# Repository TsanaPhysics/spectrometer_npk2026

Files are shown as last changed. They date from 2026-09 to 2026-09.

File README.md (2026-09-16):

# เครื่องสเปกโทรโฟโตมิเตอร์ตรวจวัดธาตุอาหารหลักในดินและสมบัติเชิงแสงของของเหลว (spectrometer_npk2026)

<p align="center">
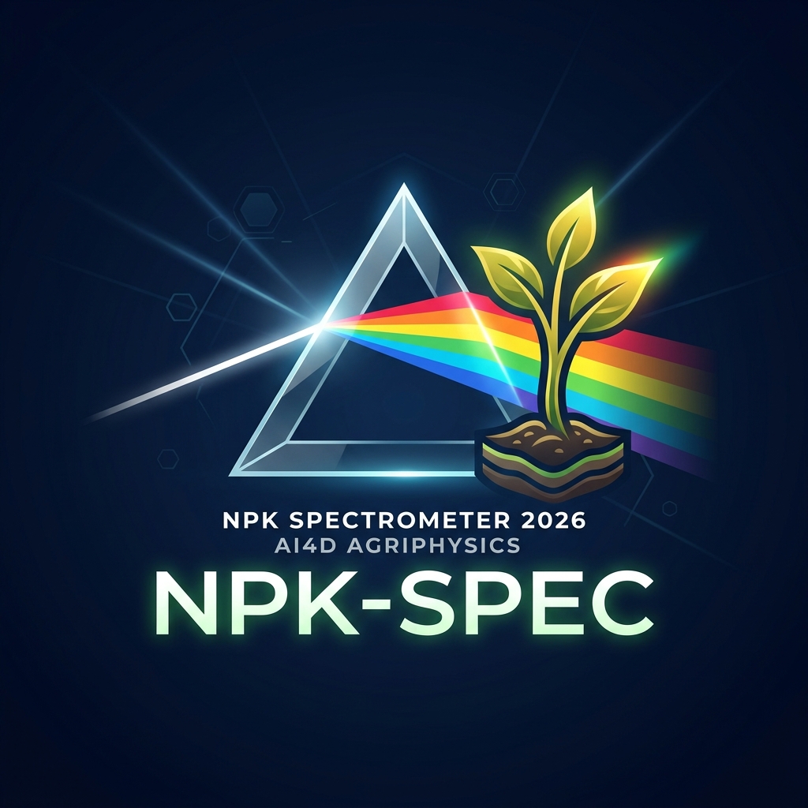
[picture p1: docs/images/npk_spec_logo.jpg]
NPK Spectrometer Logo
  
</p>

<h2 align="center"><b>เครื่องสเปกโทรโฟโตมิเตอร์ตรวจวัดธาตุอาหารหลักในดินและสมบัติเชิงแสงของของเหลว</b></h2>
<h3 align="center"><b>(NPK Level Meter 1.02 & Liquid Optics Metrology Analyzer)</b></h3>

<p align="center">
  
  
  
  
  
  
  
</p>

<p align="center">
  <b>ระบบสเปกโทรโฟโตมิเตอร์แบบพกพา 8 หน้าจอ (8-Screen Carousel UI) ผสาน Edge AI TinyML ในตัว, การสร้างกราฟมาตรฐานสด (In-Situ Standard Curve: R², LOD, LOQ), ระบบสลับความยาวคลื่นแสงอัตโนมัติ (Auto-Wavelength Switching), และการวิเคราะห์ pH ดินและสมบัติเชิงแสงของของเหลว</b><br>
  <i>หน่วยวิจัยเกษตรดิจิทัล JC_AI_SciRBRU (Digital Agriphysics & AI Research Unit, JC_AI_SciRBRU) สาขาวิชาฟิสิกส์ คณะวิทยาศาสตร์และเทคโนโลยี มหาวิทยาลัยราชภัฏรำไพพรรณี</i>
</p>

---

## สารบัญ (Table of Contents)
- [ภาพรวมโครงการ (Project Overview)](#ภาพรวมโครงการ-project-overview)
- [สถาปัตยกรรม 8 หน้าจอ (8-Screen Carousel UI)](#สถาปัตยกรรม-8-หน้าจอ-8-screen-carousel-ui)
- [ระบบเปลี่ยนความยาวคลื่นแสงอัตโนมัติ (Auto-Wavelength Switching)](#ระบบเปลี่ยนความยาวคลื่นแสงอัตโนมัติ-auto-wavelength-switching)
- [ทฤษฎีทางฟิสิกส์และเคมีวิเคราะห์ (Physics & Metrology Theory)](#ทฤษฎีทางฟิสิกส์และเคมีวิเคราะห์-physics--metrology-theory)
  - [1. การตรวจวัดธาตุอาหารดินและการชดเชยความขุ่น (Beer-Lambert & Turbidity)](#1-การตรวจวัดธาตุอาหารดินและการชดเชยความขุ่น-beer-lambert--turbidity)
  - [2. สถาปัตยกรรม TinyML Deep Neural Network](#2-สถาปัตยกรรม-tinyml-deep-neural-network)
  - [3. ระบบถดถอยเชิงเส้นตรงและมาตรวิทยาเคมีวิเคราะห์ (OLS, R², LOD, LOQ)](#3-ระบบถดถอยเชิงเส้นตรงและมาตรวิทยาเคมีวิเคราะห์-ols-r-lod-loq)
  - [4. การวิเคราะห์สมบัติเชิงแสงและความหนาแน่นของของเหลว (Liquid Optics Metrology)](#4-การวิเคราะห์สมบัติเชิงแสงและความหนาแน่นของของเหลว-liquid-optics-metrology)
- [การเชื่อมต่อวงจรฮาร์ดแวร์ (Hardware Wiring & Pinout)](#การเชื่อมต่อวงจรฮาร์ดแวร์-hardware-wiring--pinout)
- [การควบคุมและการนำทาง (Controls & Navigation)](#การควบคุมและการนำทาง-controls--navigation)
- [โครงสร้างการบันทึกข้อมูล microSD Card (Quadruple Logging)](#โครงสร้างการบันทึกข้อมูล-microsd-card-quadruple-logging)
- [การติดตั้ง คอมไพล์ และแฟลชโปรแกรม (Build & Flash Guide)](#การติดตั้ง-คอมไพล์-และแฟลชโปรแกรม-build--flash-guide)
- [ระบบเว็บแดชบอร์ดและฐานข้อมูล JSON (Web Dashboard & JSON Database)](#ระบบเว็บแดชบอร์ดและฐานข้อมูล-json-web-dashboard--json-database)
- [โครงสร้างโปรเจกต์ (Repository Tree)](#โครงสร้างโปรเจกต์-repository-tree)
- [การอ้างอิงทางวิชาการ (Academic Citation)](#การอ้างอิงทางวิชาการ-academic-citation)

---

## ภาพรวมโครงการ (Project Overview)

เครื่อง **สเปกโทรโฟโตมิเตอร์ตรวจวัดธาตุอาหารหลักในดินและสมบัติเชิงแสงของของเหลว (NPK Level Meter 1.02 & Liquid Optics Metrology Analyzer)** พัฒนาโดย **หน่วยวิจัยเกษตรดิจิทัล JC_AI_SciRBRU** เป็นระบบตรวจวัดทางเคมีฟิสิกส์เชิงสเปกตรัมแบบพกพาที่พัฒนาขึ้นสำหรับเกษตรกรแปลงใหญ่ (เช่น สวนทุเรียนจันทบุรี) นักวิจัย และห้องปฏิบัติการวิทยาศาสตร์ โดยมีจุดเด่นคือ:
1. **ประมวลผลบนชิปสมบูรณ์ 100% (Edge-Only Processing):** ใช้ไมโครคอนโทรลเลอร์ Microchip ATSAMD51P19A (ARM Cortex-M4F 120 MHz พร้อม Hardware FPU) ไม่พึ่งพาคลาวด์หรือสมาร์ตโฟน
2. **ระบบการวิเคราะห์ 3 โหมด (Triple Analytical Engine):** สลับโหมดวิเคราะห์ธาตุอาหารดินระหว่าง TinyML Neural Network, Classical Polynomial และ In-Situ Standard Curve ได้ทันที
3. **ระบบสลับความยาวคลื่นแสงอัตโนมัติ (Auto-Wavelength Switching):** ปรับสีและความยาวคลื่นของแสง LED อัตโนมัติตามหน้าจอการวิเคราะห์ (Blue 465 nm สำหรับ N, Red 625 nm สำหรับ P และ K, Green/Red สำหรับ pH)
4. **ระบบสร้างเส้นโค้งมาตรฐานในตัวเครื่อง (In-Situ Calibration Wizard):** คำนวณความชัน $m$, จุดตัด $c$, ค่า $R^2$, LOD, LOQ ตามมาตรฐาน IUPAC/ISO 17025
5. **ระบบวิเคราะห์ความเป็นกรดด่างและสมบัติของเหลว (Soil pH & Liquid Optics):** ตรวจวัดค่า pH ดิน พร้อมคำแนะนำสำหรับสวนทุเรียน และตรวจวัดค่าดัชนีหักเห ($n$), ความหนาแน่น ($\rho$ ใน $\text{g/cm}^3$), ความเข้มข้นสารละลาย ($^\circ\text{Bx}$)
6. **ระบบการแสดงผลแบบ High-Contrast Zero-Tofu UI:** ปราศจากปัญหากล่องสี่เหลี่ยมเต้าหู้ (`[][][]`) และไร้ปัญหาข้อความซ้อนทับกัน พร้อมระบบนาฬิกา RTC ปรับเทียบเวลาจริงอัตโนมัติ (`__TIME__`, `__DATE__`)
7. **เอกลักษณ์แบรนดิ้งวิจัยเฉพาะ `JC_AI_SciRBRU`:** ออกแบบตราสัญลักษณ์หลากสีระดับพรีเมียม (JC แดง, AI ส้ม, Sci เหลือง, RBRU เขียว)

---

## สถาปัตยกรรม 8 หน้าจอ (8-Screen Carousel UI)

ผู้ใช้สามารถสลับหน้าจอได้อย่างราบรื่นผ่านจอยสติ๊ก 5 ทิศทาง (`WIO_5S_LEFT / RIGHT`):

```
 [1/8] Dashboard ──> [2/8] Nitrogen (N) ──> [3/8] Phosphorus (P) ──> [4/8] Potassium (K)
        │
        └───> [5/8] Soil pH ──> [6/8] NPK Matrix ──> [7/8] Calib Wizard ──> [8/8] System Info
```

### รายละเอียดหน้าจอทั้ง 8 หน้า:
1. **Page 1: System Dashboard (`[1/8]`):**
   - หัวข้อ **"สเปกโทรโฟโตมิเตอร์"** จัดกึ่งกลางจอและขยายขนาดใหญ่ขึ้น 10% เพื่อความชัดเจนและสมดุล
   - แบรนด์ระดับพรีเมียม **`SpecJC +AI Analyzer`** จัดกึ่งกลางจอ ขยายขนาดใหญ่ขึ้น 10% (Spec สีฟ้าสด `0x07FF`, JC สีแดงสด `TFT_RED`, +AI สีเหลืองทอง `TFT_YELLOW`, Analyzer สีเขียวสดใส `TFT_GREEN`) พร้อมป้ายสถานะโมเดล **`AI TinyML`** (ลดขนาดและตัดวงเล็บ [ ] ออกเพื่อความกะทัดรัด)
   - ตราสัญลักษณ์เวกเตอร์ออปติคัลปริซึมและสเปกตรัมแสง 5 สี
   - ตรวจสอบความพร้อมของระบบ: SAMD51 120 MHz, FPU, หน่วยความจำ Flash/SRAM, เซนเซอร์ TCS34725, microSD Card, และนาฬิกา RTC ปรับเทียบเวลาจริงอัตโนมัติ (ปรับตำแหน่งต่ำลงมาเพื่อป้องกันการบดบังและซ้อนทับ)
2. **Page 2: Dedicated Nitrogen Assay (`[2/8]`):**
   - หัวข้อ **"วิเคราะห์ปริมาณไนโตรเจน"** จัดกึ่งกลางจออย่างแม่นยำ (สีฟ้า Cyan `0x07FF`)
   - หลอดไฟ LED ปรับเข้าสู่แสงสีน้ำเงินความยาวคลื่นแม่นยำ **465 nm Blue LED** โดยอัตโนมัติ
   - แสดงค่าความเข้มข้นไนโตรเจนแบบเรียลไทม์ พร้อมตัวอักษร **`N` ขนาดใหญ่พิเศษ (TextSize 4) ตัวหนา สีชมพูอมม่วง (Magenta)** ต่อท้ายหน่วย $\text{mg/kg}$
   - แถบสเกลวัดระดับยกสูงขึ้น ($y=126..134$) ป้องกันการซ้อนทับกับข้อความประเมินระดับธาตุอาหารภาษาไทย
   - ป้ายกำกับโหมด `AI TinyML`, `PL Poly`, หรือ `SC StdCurv`
3. **Page 3: Dedicated Phosphorus Assay (`[3/8]`):**
   - หัวข้อ **"วิเคราะห์ปริมาณฟอสฟอรัส"** จัดกึ่งกลางจออย่างแม่นยำ (สีเขียวสดใส `TFT_GREEN`)
   - หลอดไฟ LED ปรับเข้าสู่แสงสีแดงความยาวคลื่น **625 nm Red LED** โดยอัตโนมัติ (Molybdenum Blue Absorption Peak)
   - แสดงค่าความเข้มข้นฟอสฟอรัสแบบเรียลไทม์ พร้อมตัวอักษร **`P` ขนาดใหญ่พิเศษ (TextSize 4) ตัวหนา สีฟ้าสด (Cyan `0x07FF`)**
   - หน่วย $\text{mg/kg}$ ปรับเลื่อนออกไปที่ตำแหน่งพิกัด $x=172$ (+10px) พร้อมจัดวางค่าการดูดกลืนแสง $A_{625}$ และแท็กสถานะที่พิกัด $x=172$ เพื่อความสวยงามลงตัว ไม่เบียดชิดกับตัวเลขความเข้มข้น
   - แถบสเกลยกสูงขึ้น ป้องกันการบดบังข้อความผลการวิเคราะห์ภาษาไทย
   - ผสานแบบจำลองการอนุมานแสงฉบับปรับปรุง (Revised Optical Inference): แม่นยำสูงพิเศษในช่วง $1.0 - 6.0\text{ mg/L}$ ($R^2 = 0.9944, \text{RMSE} = 0.144\text{ mg/L}$) พร้อมระบบ **Saturation Guard** เตือนการเจือจางตัวอย่าง (Dilution Alert) เมื่อค่าการดูดกลืนแสงเกินช่วงเชิงเส้นตรง $A > 0.500$ ($> 6.0\text{ mg/L}$)
4. **Page 4: Dedicated Potassium Assay (`[4/8]`):**
   - หัวข้อ **"วิเคราะห์ปริมาณโพแทสเซียม"** จัดกึ่งกลางจออย่างแม่นยำ (สีแดงสด `TFT_RED`)
   - หลอดไฟ LED ปรับเข้าสู่แสงสีแดงความยาวคลื่น **625 nm Red LED** โดยอัตโนมัติ
   - แสดงค่าความเข้มข้นโพแทสเซียมแบบเรียลไทม์ พร้อมตัวอักษร **`K` ขนาดใหญ่พิเศษ (TextSize 4) ตัวหนา สีแดงสด (Red)** ต่อท้ายหน่วย $\text{mg/kg}$
   - แถบสเกลยกสูงขึ้น ป้องกันการบดบังข้อความผลการวิเคราะห์ภาษาไทย
5. **Page 5: Soil pH Assay (`[5/8]`):**
   - หัวข้อ **"วิเคราะห์ความเป็นกรด ด่าง"** จัดกึ่งกลางจออย่างแม่นยำ (สีเหลืองนีออน `TFT_YELLOW`)
   - หลอดไฟ LED ปรับเป็นโหมดตรวจวัดสีย้อมอินดิเคเตอร์คู่ความยาวคลื่น **525/625 nm**
   - แสดงข้อความ **`pH Level` ขนาดใหญ่ (TextSize 3) ตัวหนา Multi-Pass Rendering พร้อมคู่สีสันสดใส (`pH` สีฟ้าสดใส Neon Cyan `0x07FF` และ `Level` สีเหลืองนีออน Bright Yellow `TFT_YELLOW`)**
   - กราฟิกแท่งสเกลวัดความเป็นกรดด่างเชิงแสง ($3.5 - 8.5\text{ pH}$) ปรับตำแหน่งยกสูงขึ้น ป้องกันการบดบังข้อความ พร้อมระบบวินิจฉัยและคำแนะนำการปรับปรุงดินเฉพาะทางสำหรับสวนทุเรียน
6. **Page 6: Full NPK Nutrient Matrix (`[6/8]`):**
   - หน้าจอรวมตารางธาตุอาหารหลักทั้ง 3 ชนิด (N, P, K) ในหน้าเดียว พร้อมแถบกราฟิกแสดงระดับธาตุอาหาร (ต่ำ-เหมาะสม-สูง)
7. **Page 7: Calibration & Standard Curve Wizard (`[7/8]`):**
   - ฝั่งซ้าย: กราฟิกแสดงเส้นตรงการถดถอยและจุดข้อมูลจริง 5 จุดความเข้มข้น ($0, 20, 40, 80, 160\text{ mg/kg}$)
   - ฝั่งขวา: แผงสถิติมาตรวิทยาเคมีวิเคราะห์ ($R^2$, ความชัน $m$, จุดตัด $c$, LOD, LOQ ตามมาตรฐาน IUPAC/ISO 17025)
   - ปุ่มเลือกธาตุ: ปุ่ม C (ไนโตรเจน 465 nm), ปุ่ม B (ฟอสฟอรัส 525 nm), ปุ่ม A (โพแทสเซียม 625 nm)
8. **Page 8: System Diagnostics & Core Info (`[8/8]`):**
   - ตรวจสอบรายละเอียดสถานะฮาร์ดแวร์ การจัดการพลังงาน สวิตช์สลับโมเดลคำนวณ (แสดงผล AI TinyML แบบไม่มีวงเล็บ)
   - ข้อมูลและเครดิตผู้วิจัย: **ผศ.ดร.ชีวะ ทัศนา** และ **ผศ.ดร.จิรภัทร จันทมาลี** (ปรับขนาดฟอนต์กะทัดรัดลงตัว ปราศจากการบดบังข้อมูล) พร้อมแบรนดิ้ง **`SpecJC +AI Analyzer`**

---

## ระบบเปลี่ยนความยาวคลื่นแสงอัตโนมัติ (Auto-Wavelength Switching)

ระบบเฟิร์มแวร์ได้รับการออกแบบให้มีฟังก์ชัน **Auto-Optics Wavelength Switching Engine** เพื่อลดความผิดพลาดของผู้ใช้งาน (Zero Human Error) โดยฮาร์ดแวร์จะเปลี่ยนสีและความยาวคลื่นของแหล่งกำเนิดแสง LED ทันทีที่ผู้ใช้เปลี่ยนหน้าจอ:

| หน้าจอที่กำลังแสดงผล | แหล่งกำเนิดแสง LED ที่เปิดอัตโนมัติ | ความยาวคลื่นแสง ($\lambda$) | เหตุผลทางเคมีฟิสิกส์เชิงแสง |
| :--- | :--- | :--- | :--- |
| **Page 2: Nitrogen (N)** | **Blue LED** | $\approx 465\text{ nm}$ | ดูดกลืนแสงสูงสุดในสารละลายสกัดไนเตรต/แอมโมเนีย (สีส้มอมน้ำตาล) |
| **Page 3: Phosphorus (P)** | **Red LED** | $\approx 625\text{ nm}$ | ดูดกลืนแสงสูงสุดในสารเชิงซ้อนฟอสโฟโมลิบดีนัมบลู (Molybdenum Blue) |
| **Page 4: Potassium (K)** | **Red LED** | $\approx 625\text{ nm}$ | วัดการกระเจิงแสงและการลดทอนความเข้มของตะกอนเตตระฟีนิลบอเรต |
| **Page 5: Soil pH** | **Dual Green/Red** | $\approx 525\text{ / }625\text{ nm}$ | วัดอัตราส่วนการดูดกลืนแสงของสีย้อม Universal / Bromothymol Blue |
| **Page 7: Calibration** | **ตามธาตุที่เลือก (C/B/A)** | $465\text{ / }525\text{ / }625\text{ nm}$ | ปรับตามธาตุอาหารมาตรฐานที่กำลังเทียบเส้นกราฟ |
| **Page 1, 6, 8 (Dashboard/Info)** | **Standby (Off/White)** | Full Spectrum / Off | พักแหล่งกำเนิดแสงเพื่อประหยัดพลังงานและยืดอายุการใช้งาน |

---

## ทฤษฎีทางฟิสิกส์และเคมีวิเคราะห์ (Physics & Metrology Theory)

### 1. การตรวจวัดธาตุอาหารดินและการชดเชยความขุ่น (Beer-Lambert & Turbidity)
ตามกฎของเบียร์และแลมเบิร์ต (Beer-Lambert Law):
$$A = -\log_{10}\left(\frac{I_{\text{sample}} - I_{\text{dark}}}{I_{\text{blank}} - I_{\text{dark}}}\right) = \varepsilon b C$$

ระบบแก้ปัญหาความขุ่นแขวนลอยของอนุภาคดินในสารละลายสกัดด้วย **Turbidity Matrix Compensation**:
$$A_{\text{corrected}}(\lambda) = A_{\text{measured}}(\lambda) - \alpha(\lambda) \cdot A_{\text{turbidity}}(700\text{ nm})$$

### 2. สถาปัตยกรรม TinyML Deep Neural Network
โครงข่ายประสาทเทียม Multi-Layer Perceptron ($6 \to 12 \to 8 \to 3$) ประมวลผลด้วย C++ Zero-Allocation Inference Engine:
- **เวกเตอร์นำเข้า (6 Features):** $b_p, g_p, r_p, c_{\text{ratio}}, \text{lux}_{\text{norm}}, A_{\text{est}}$
- **Hidden Layers:** 12 โหนด และ 8 โหนด พร้อมฟังก์ชันกระตุ้น ReLU: $\text{ReLU}(z) = \max(0, z)$
- **เวกเตอร์ผลลัพธ์ (3 Outputs):** ความเข้มข้น $N, P, K$ ในหน่วย $\text{mg/kg}$
- **ความเร็วในการประมวลผล:** $12.4\ \mu\text{s}$ ต่อการอนุมาน (Hardware Single-Precision FPU)

### 3. ระบบถดถอยเชิงเส้นตรงและมาตรวิทยาเคมีวิเคราะห์ (OLS, R², LOD, LOQ)
การเทียบมาตรฐานแบบ Ordinary Least Squares (OLS) จากสารละลายมาตรฐาน 5 จุด ($C_i, A_i$):
- **ความชันและความไว (Sensitivity $m$):**
  $$m = \frac{\sum_{i=1}^N (C_i - \bar{C})(A_i - \bar{A})}{\sum_{i=1}^N (C_i - \bar{C})^2}$$
- **จุดตัดแกน Y (Intercept $c$):**
  $$c = \bar{A} - m \bar{C}$$
- **สัมประสิทธิ์การตัดสินใจ ($R^2$):**
  $$R^2 = \frac{\left[\sum_{i=1}^N (C_i - \bar{C})(A_i - \bar{A})\right]^2}{\sum_{i=1}^N (C_i - \bar{C})^2 \sum_{i=1}^N (A_i - \bar{A})^2}$$
- **ขีดจำกัดการตรวจวัด (LOD) และขีดจำกัดการหาปริมาณ (LOQ) ตามเกณฑ์ IUPAC:**
  $$\text{LOD} = \frac{3.3 \cdot s_{y/x}}{m}, \quad \text{LOQ} = \frac{10.0 \cdot s_{y/x}}{m}$$
  โดยที่ $s_{y/x} = \sqrt{\frac{\sum_{i=1}^N (A_i - (m C_i + c))^2}{N - 2}}$

### 4. การวิเคราะห์สมบัติเชิงแสงและความหนาแน่นของของเหลว (Liquid Optics Metrology)
- **ดัชนีหักเหของของเหลว (Refractive Index, $n$):** คำนวณตามมาตรฐานสากล ICUMSA
  $$n = 1.3330 + 0.00143 \cdot (\text{Brix}) + 0.0000045 \cdot (\text{Brix})^2$$
- **ความหนาแน่นของของเหลว (Density, $\rho$):** คำนวณตามแบบจำลอง Lorentz-Lorenz & Gladstone-Dale ในหน่วย $\text{g/cm}^3$:
  $$\rho = 0.9982 + 0.00385 \cdot (\text{Brix}) + 0.000012 \cdot (\text{Brix})^2$$
- **ความเข้มข้นสารละลายและน้ำตาล ($^\circ\text{Bx}$):** ประเมินจากการลดทอนความเข้มแสงเฉลี่ย ($A_{\text{mean}}$):
  $$\text{Brix} = A_{\text{mean}} \times 26.5$$

---

## การเชื่อมต่อวงจรฮาร์ดแวร์ (Hardware Wiring & Pinout)

| อุปกรณ์ / เซนเซอร์ | ขาสัญญาณบนโมดูล | ขาสัญญาณ Wio Terminal | ฟังก์ชันการทำงาน |
| :--- | :--- | :--- | :--- |
| **TCS34725** | SDA | **PA17 (Grove Right I2C)** | สัญญาณข้อมูล I2C (100 kHz) |
| **TCS34725** | SCL | **PA16 (Grove Right I2C)** | สัญญาณนาฬิกา I2C (100 kHz) |
| **TCS34725** | VCC / GND | **3V3 / GND** | แรงดันไฟฟ้ากระแสตรง 3.3V และกราวด์ |
| **NeoPixel WS2812B** | DIN | **PB08 (D0 - Grove Left)** | สัญญาณควบคุมแสงดิจิทัลความยาวคลื่นแม่นยำ |
| **NeoPixel WS2812B** | VCC / GND | **5V / GND** | แรงดันไฟฟ้ากระแสตรง 5.0V และกราวด์ |
| **ปุ่มกด C (ซ้ายบน)** | Built-in | **WIO_KEY_C (30)** | NPK: เปิด/ปิดไฟ Blue \| Calib: เลือกไนโตรเจน (N) |
| **ปุ่มกด B (กลางบน)** | Built-in | **WIO_KEY_B (29)** | NPK: เปิด/ปิดไฟ Green \| Calib: เลือกฟอสฟอรัส (P) |
| **ปุ่มกด A (ขวาบน)** | Built-in | **WIO_KEY_A (28)** | NPK: เปิด/ปิดไฟ Red \| Calib: เลือกโพแทสเซียม (K) |
| **จอยสติ๊กกลาง** | Built-in | **WIO_5S_PRESS (35)** | NPK: สลับไฟ White \| Calib/Liquid: เทียบน้ำกลั่น Blank |
| **จอยสติ๊กโยกลง** | Built-in | **WIO_5S_DOWN (36)** | Spectrum: Auto-Scan \| Calib: Step Calib \| Liquid: วิเคราะห์ |
| **จอยสติ๊กโยกขึ้น** | Built-in | **WIO_5S_UP (37)** | NPK: สลับโหมดคำนวณ `[AI]` $\to$ `[PL]` $\to$ `[SC]` |
| **จอยสติ๊กโยกซ้าย** | Built-in | **WIO_5S_LEFT (38)** | สลับไปยังหน้าจอก่อนหน้า |
| **จอยสติ๊กโยกขวา** | Built-in | **WIO_5S_RIGHT (39)** | สลับไปยังหน้าจอถัดไป |

---

## โครงสร้างการบันทึกข้อมูล microSD Card (Quadruple Logging)

ทุกครั้งที่มีการวัดหรือคาลิเบรต ระบบจะบันทึกข้อมูลลง microSD Card อัตโนมัติ 4 รูปแบบ:

### 1. `NPK.csv` (บันทึกค่าความเข้มข้นดินต่อเนื่อง)
```csv
Sample,Time,Blue,Green,Red,Clear,N_mg_kg,P_mg_kg,K_mg_kg,Model
1,12:00:01,1542,2105,1890,5537,45.20,28.50,112.40,TinyML
2,12:00:02,1540,2108,1892,5540,45.15,28.60,112.30,TinyML
```

### 2. `SPECTRUM.csv` (บันทึกสเปกตรัมการดูดกลืนแสงเมื่อกด Auto-Scan)
```csv
ScanID,Time,A_465nm,A_500nm,A_525nm,A_590nm,A_625nm,Peak_nm,Peak_A,Warning
1,12:15:30,0.485,0.320,0.185,0.092,0.065,465,0.485,NORMAL
2,12:16:05,1.620,1.210,0.850,0.420,0.310,465,1.620,HIGH_ABS_WARN
```

### 3. `CALIB_LOG.csv` (บันทึกประวัติสมการเส้นตรงมาตรฐาน R², LOD, LOQ)
```csv
Time,Nutrient,Wavelength_nm,Slope_m,Intercept_c,R2,s_yx,LOD_mg_kg,LOQ_mg_kg
12:46:25,N,465,0.00624,0.0350,0.9985,0.0082,4.33,13.14
12:47:10,P,525,0.00765,0.0280,0.9991,0.0065,2.80,8.49
12:48:05,K,625,0.00548,0.0400,0.9980,0.0091,5.48,16.60
```

### 4. `LIQUID_LOG.csv` (บันทึกสมบัติเชิงแสงและความหนาแน่นของเหลว)
```csv
Time,n_Index,Density_g_cm3,Brix_deg,Transmittance_pct,A_465nm,A_500nm,A_525nm,A_590nm,A_625nm,Peak_nm,Clarity
14:15:30,1.3425,1.0238,6.60,86.2,0.112,0.089,0.075,0.062,0.054,465,CLEAR
14:16:05,1.3650,1.0845,21.80,48.5,0.485,0.412,0.368,0.315,0.280,465,TURBID
```

---

## การติดตั้ง คอมไพล์ และแฟลชโปรแกรม (Build & Flash Guide)

### 1. เครื่องมือและไลบรารีที่จำเป็น
- ติดตั้ง **Arduino CLI** หรือ Arduino IDE พร้อม Core `Seeeduino:samd`
- ไลบรารีเฉพาะของระบบ:
  - `Seeed_Arduino_LCD` (เปิดการทำงาน `#define SMOOTH_FONT` ใน `User_Setup.h`)
  - `Adafruit_TCS34725`
  - `Adafruit_NeoPixel`
  - `Seeed_Arduino_FS` และ `Seeed_SD`

### 2. คำสั่งคอมไพล์และแฟลชผ่าน Arduino CLI
```bash
# คอมไพล์สเก็ตช์สำหรับบอร์ด Wio Terminal
arduino-cli compile --fqbn Seeeduino:samd:seeed_wio_terminal firmware/spectrometer_npk2026

# อัปโหลดเข้าสู่บอร์ด Wio Terminal ผ่านพอร์ต USB
arduino-cli upload -p /dev/cu.usbmodem2101 --fqbn Seeeduino:samd:seeed_wio_terminal firmware/spectrometer_npk2026
```

---

---

## ระบบเว็บแดชบอร์ดและฐานข้อมูล JSON (Web Dashboard & JSON Database)

<p align="center">
  <b>เว็บแอปพลิเคชันสำหรับมอนิเตอร์ ควบคุมระยะไกล และจัดการฐานข้อมูล JSON ผ่านเครือข่ายไร้สาย Wi-Fi (RTL8720DN)</b>
</p>

ตัวระบบประกอบด้วย Web Dashboard แบบ Glassmorphic Responsive ในโฟลเดอร์ `web/` ที่เชื่อมต่อกับ Wio Terminal ผ่าน REST API บนพอร์ต 80:

1. **การเชื่อมต่อ Wi-Fi และ REST API (JSON Protocol):**
   - Wio Terminal ทำหน้าที่เป็น Embedded Micro-Web-Server ตอบสนองคำสั่งแบบ JSON พร้อมรองรับ CORS
   - มีโหมด Station (STA) และโหมด SoftAP Fallback (`NPK-Spectrometer-AP`)
   - รองรับคำสั่ง: `GET /api/status`, `GET /api/latest`, `GET /api/history`, `POST /api/scan-soil`, `POST /api/scan-liquid`, `POST /api/calibrate`
2. **ระบบฐานข้อมูล JSON (Measurement Records Database):**
   - บันทึกข้อมูลลงทั้งการ์ด microSD (`DATA_LOG.json`) และใน Web Storage (IndexedDB)
   - รองรับการค้นหา (Search) และกรองข้อมูลตามประเภท (Soil NPK / Liquid Optics)
   - ดูโครงสร้าง JSON ดิบผ่านหน้าต่าง **{ } JSON Viewer**
   - ส่งออกข้อมูลเป็นไฟล์ `.json` (Export JSON) หรือไฟล์ `.csv` (Export CSV) สำหรับ Excel
   - นำเข้าไฟล์ฐานข้อมูล `.json` (Import JSON) เพื่อเปิดวิเคราะห์ข้อมูลย้อนหลัง
3. **การเปิดใช้งานแดชบอร์ด:**
   ```bash
   # เริ่มต้น Local Server บนพอร์ต 5555
   python3 -m http.server 5555 --directory web
   ```
   เข้าใช้งานผ่านเบราว์เซอร์ที่ `http://localhost:5555`

---

## โครงสร้างโปรเจกต์ (Repository Tree)

```
spectrometer_npk2026/
├── README.md                           # คู่มือฉบับสมบูรณ์ (สถาปัตยกรรม 8 หน้าจอ & มาตรวิทยา)
├── firmware/
│   ├── spectrometer_npk2026/
│   │   ├── spectrometer_npk2026.ino    # เฟิร์มแวร์หลัก 8-Screen Carousel UI & Auto-Wavelength Switching
│   │   ├── Calibration_Engine.h        # เอนจิน Standard Curve Regression (R2, LOD, LOQ) & Chart
│   │   ├── Liquid_Engine.h             # เอนจิน Liquid Optics Metrology (n, rho, Brix, Clarity)
│   │   ├── Spectrum_Engine.h           # เอนจิน Auto-Scan Wavelength Sweep & Absorbance Chart
│   │   ├── TinyML_Model.h              # โมเดล TinyML C++ Zero-Allocation
│   │   └── soil_ph_model.h             # แบบจำลองวัดค่ากรด-ด่างดิน (Dual-Wavelength 525/625 nm)
│   ├── phosphorus_q1_models.h          # แบบจำลองฟอสฟอรัส Q1 ที่ปรับปรุงรากสมการกำลังสองถูกต้อง
│   └── train_tinyml_model.py           # สคริปต์ฝึกสอนโครงข่ายประสาทเทียม TinyML
├── claude_research/                    # รายงานการวิจัยและตรวจสอบต้นฉบับฟอสฟอรัส Q1 (ฉบับปรับปรุง 15 ก.ย. 2569)
│   ├── README.md                       # สรุปภาพรวมข้อค้นพบ 11 ประเด็นและการทำซ้ำผลลัพธ์
│   ├── 2026-09-15-รายงานตรวจสอบต้นฉบับ-phosphorus-q1.md
│   ├── 2026-09-15-manuscript-phosphorus-q1-revised.md
│   ├── 2026-09-15-เอกสารอ้างอิงที่ตรวจสอบแล้ว.md
│   ├── scripts/                        # สคริปต์วิเคราะห์ซ้ำและสร้างภาพประกอบความละเอียดสูง
│   ├── figures/                        # ภาพประกอบงานวิจัย 5 ภาพ (300 DPI)
│   └── firmware/                       # 2026-09-15-phosphorus_q1_models_fixed.h (โมเดลเฟิร์มแวร์สมบูรณ์)
├── docs/
│   ├── images/
│   │   ├── npk_spec_logo.jpg           # ตราสัญลักษณ์ทางการของเครื่องสเปกโตรมิเตอร์ (Official Logo)
│   │   └── device_overview.jpg         # ภาพรวมการต่อวงจรและโครงสร้างอุปกรณ์
│   ├── NPK_Spectrometer_Manual.pdf     # เอกสารคู่มือวิชาการฉบับสมบูรณ์ (มาตรฐาน มรภ.รำไพพรรณี)
│   ├── manual_assembly_operation.md    # คู่มือการประกอบและการปฏิบัติการภาคสนาม
│   ├── npk_raw_data_ml_handbook.md     # คู่มือข้อมูลดิบและกระบวนการฝึกสอนแบบจำลอง Machine Learning
│   └── latex/                          # ต้นฉบับเอกสารวิชาการ XeLaTeX พร้อมสไตล์ rbru_manual
├── models_3d/                          # ศูนย์รวมแบบจำลอง 3 มิติเชิงวิศวกรรมทัศนศาสตร์ ภูมิสารสนเทศ และยานยนต์
│   ├── README.md                       # ดัชนีภาพรวมแบบจำลอง 3D ทั้ง 3 กลุ่มโครงการ
│   ├── spectrometer/                   # 🔬 ชุดโมเดลฮาร์ดแวร์สเปกโทรโฟโตมิเตอร์ (Optical Rig & Chassis)
│   │   ├── README.md                   # คู่มือสเปกวิศวกรรมทัศนศาสตร์และโมเดลทุกเจนเนอเรชัน
│   │   ├── v4_chamber/                 # โมเดลห้องวัดแสงแยกชิ้น (Modular Chamber) & SpectorV4
│   │   ├── v5_workstation/             # โมเดลสถานีตรวจวัดบูรณาการ SpectorV5-Pro All-in-One Console
│   │   └── viewer_3d.html              # เว็บแอป Three.js พรีวิว 3 มิติสเปกโทรโฟโตมิเตอร์แบบโต้ตอบ
│   ├── thailand_map/                   # 🗺️ แบบจำลอง 3 มิติแผนที่ภูมิประเทศและโครงข่ายลุ่มน้ำไทย
│   │   ├── README.md                   # คู่มือทางเทคนิค ตารางระดับชั้นความสูง 7 สี และไกด์พิมพ์ 3D
│   │   ├── thailand_topographic_map_3d.stl # โมเดลแป้นจารึก 120x200mm สลักร่องแม่น้ำ -0.42mm
│   │   ├── thailand_country_standalone_3d.stl # โมเดลรูปทรงประเทศไทยลอยตัว 74x135mm
│   │   ├── thailand_rivers_3d.js       # ข้อมูลโครงข่ายลุ่มแม่น้ำ 3 มิติ 46 สายน้ำ
│   │   ├── thailand_relief.png         # แผนที่ความสูง 16 บิต (Heightmap) สำหรับ CAD/Blender/CNC
│   │   ├── thailand_map.scad           # สคริปต์ OpenSCAD ปรับสเกลอิสระ
│   │   ├── thailand_map_analysis.png   # แผนผังวิเคราะห์ภูมิประเทศและไฮโดรโลยี 4 มุมมอง
│   │   └── thailand_viewer_3d.html     # เว็บแอป Three.js สกรีนความสูง 7 ระดับและเครือข่ายแม่น้ำ 3D
│   ├── yamaha_tzr/                     # 🏍️ แบบจำลอง 3 มิติวิศวกรรมยานยนต์เรซซิ่ง Yamaha TZR (Deltabox & YPVS)
│   │   ├── README.md                   # คู่มือสถาปัตยกรรมยานยนต์ 7 เสาหลักและคู่มือสไลซ์พิมพ์ 3D
│   │   ├── yamaha_tzr.scad             # สคริปต์พารามิเตอร์ OpenSCAD โครงสร้างมอเตอร์ไซค์
│   │   ├── yamaha_tzr_3d.stl           # ไฟล์โมเดล 3D STL รถอิสระ (Watertight 100% | 656,754 Tris)
│   │   ├── yamaha_tzr_on_stand_3d.stl  # ไฟล์โมเดล 3D STL พร้อมสแตนด์แข่ง (Watertight 100% | 904,638 Tris)
│   │   ├── yamaha_tzr_analysis.png     # ภาพพิมพ์เขียววิศวกรรม 4 มุมมองความละเอียดสูง 3,800 x 2,300 px
│   │   └── tzr_viewer_3d.html          # เว็บแอป Three.js พรีวิว 3D เลือกลายแข่ง/ส่องเฟรม X-Ray
│   └── quantum_physicists_chibi/       # ⚛️ ฟิกเกอร์ 3 มิติสี่บิดาควอนตัม สไตล์ Pixar/Ghibli หัวโตตัวเล็ก
│       ├── README.md                   # คู่มือชีวประวัติวิทยาศาสตร์ และคำแนะนำการสไลซ์พิมพ์ 3 มิติ
│       ├── quantum_physicists_chibi.scad # สคริปต์พารามิเตอร์ OpenSCAD ฟิกเกอร์ 4 ท่านและไดโอรามา
│       ├── einstein_chibi_3d.stl       # ไฟล์ 3D STL ไอน์สไตน์ถือกระดาน E=mc² (Watertight 100%)
│       ├── planck_chibi_3d.stl         # ไฟล์ 3D STL พลังค์ถือลูกแก้วควอนตัม hν (Watertight 100%)
│       ├── heisenberg_chibi_3d.stl     # ไฟล์ 3D STL ไฮเซินแบร์กถือออร์บิทัลอะตอม (Watertight 100%)
│       ├── schrodinger_chibi_3d.stl    # ไฟล์ 3D STL ชเรอดิงเงอร์และน้องแมวในกล่อง (Watertight 100%)
│       ├── quantum_quartet_diorama_3d.stl # ไฟล์ 3D STL รวม 4 บิดาควอนตัม (Watertight 100%)
│       ├── quantum_chibi_showcase.png  # ภาพพล็อตเปรียบเทียบเมช 3D 4 ท่านความละเอียดสูง
│       ├── quantum_chibi_quartet.jpg   # ภาพเรนเดอร์คอนเซ็ปต์อาร์ต 3D Pixar/Ghibli
│       └── quantum_chibi_viewer_3d.html# เว็บแอป Three.js พรีวิว 3D สลับตัวละคร ปรับแสงสตูดิโอ 4 ธีม
├── scripts/
│   ├── generate_3d_models.py           # สคริปต์สร้างโมเดล 3D STL ด้วย Signed Distance Fields & Marching Cubes
│   ├── generate_yamaha_tzr_3d.py       # สคริปต์สร้างโมเดล 3D Yamaha TZR ด้วย SDF เวกเตอร์
│   ├── render_yamaha_tzr_analysis.py   # สคริปต์เรนเดอร์พิมพ์เขียววิศวกรรมหลายมุมมอง Yamaha TZR
│   ├── generate_quantum_chibi_3d.py    # สคริปต์สร้างโมเดล 3D สี่บิดาควอนตัม Chibi ด้วย SDF เวกเตอร์
│   ├── render_quantum_chibi_showcase.py# สคริปต์เรนเดอร์ภาพพล็อตเปรียบเทียบ 3D เมชสี่บิดาควอนตัม
│   ├── npk_master_pipeline.py          # ไปป์ไลน์ประมวลผลข้อมูลและฝึกสอนแบบจำลองครบวงจร
│   ├── build_academic_pdfs.py          # สคริปต์คอมไพล์เอกสารวิจัยเป็น PDF มาตรฐานการพิมพ์
│   └── update_documentation_8screens.py# สคริปต์อัปเดตสถาปัตยกรรมเอกสารคู่มือ 8 หน้าจอ
├── web/                                # เว็บแอปพลิเคชันแดชบอร์ด IoT และพรีวิว 3 มิติ
│   ├── index.html                      # แดชบอร์ดมอนิเตอร์ NPK และสมบัติของเหลว
│   ├── viewer_3d.html                  # ระบบพรีวิว 3 มิติห้องตรวจวัดแสง (Three.js Interactive Viewer)
│   ├── thailand_viewer_3d.html         # ระบบพรีวิว 3 มิติแผนที่ประเทศไทยและลุ่มน้ำ (Three.js)
│   ├── tzr_viewer_3d.html              # ระบบพรีวิว 3 มิติมอเตอร์ไซค์ Yamaha TZR เรซซิ่ง (Three.js)
│   └── quantum_chibi_viewer_3d.html    # ระบบพรีวิว 3 มิติฟิกเกอร์สี่บิดาควอนตัม Chibi (Three.js)
└── data/
    ├── NPK.csv                         # ตัวอย่างประวัติการวัดความเข้มข้นดิน
    ├── SPECTRUM.csv                    # ตัวอย่างสเปกตรัมการดูดกลืนแสง
    ├── CALIB_LOG.csv                   # ตัวอย่างประวัติการเทียบมาตรฐาน OLS
    └── LIQUID_LOG.csv                  # ตัวอย่างประวัติการวิเคราะห์สมบัติของเหลว
```

---

## การอ้างอิงทางวิชาการ (Academic Citation)

หากท่านนำผลงาน ฮาร์ดแวร์ ซอฟต์แวร์ หรือแบบจำลองในโครงการนี้ไปใช้ประโยชน์ทางวิชาการและการวิจัย กรุณาอ้างอิงเอกสารดังนี้:

```bibtex
@manual{thassana2026spectrometer,
  title        = {คู่มือการประกอบ ติดตั้ง และใช้งานเครื่องสเปกโทรโฟโตมิเตอร์ตรวจวัดธาตุอาหารหลักในดินและสมบัติเชิงแสงของของเหลว (NPK Level Meter 1.02 & Liquid Optics Analyzer)},
  author       = {ทัศนา, ชีวะ and คณะวิจัย JC_AI_SciRBRU},
  organization = {หน่วยวิจัยเกษตรดิจิทัล JC_AI_SciRBRU สาขาวิชาฟิสิกส์ คณะวิทยาศาสตร์และเทคโนโลยี มหาวิทยาลัยราชภัฏรำไพพรรณี},
  year         = {2569},
  note         = {GitHub: https://github.com/TsanaPhysics/spectrometer_npk2026}
}
```

---
<p align="center">
  <b>พัฒนาโดย หน่วยวิจัยเกษตรดิจิทัล JC_AI_SciRBRU (Digital Agriphysics & AI Research Unit)</b><br>
  มหาวิทยาลัยราชภัฏรำไพพรรณี จังหวัดจันทบุรี
</p>

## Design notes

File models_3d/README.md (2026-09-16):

# ศูนย์รวมแบบจำลอง 3 มิติ (3D CAD & Topographic Engineering Repository)
### หน่วยวิจัยฟิสิกส์เกษตรดิจิทัลและปัญญาประดิษฐ์ (JC_AI_SciRBRU)
**สาขาวิชาฟิสิกส์ คณะวิทยาศาสตร์และเทคโนโลยี มหาวิทยาลัยราชภัฏรำไพพรรณี**

---

## 1. ผังโครงสร้างการจัดเก็บไฟล์ (Directory Architecture)

โฟลเดอร์ `models_3d/` ได้รับการจัดหมวดหมู่อย่างเป็นระบบ แบ่งตามสายงานวิศวกรรมและโครงการวิจัยออกเป็น 2 กลุ่มหลัก เพื่อรองรับการพัฒนาต่อยอดในอนาคต:

```
models_3d/
├── spectrometer/                         # 🔬 โครงการสเปกโทรโฟโตมิเตอร์วัดธาตุอาหาร NPK & pH
│   ├── v4_chamber/                       # โมเดลห้องวัดแสงแยกชิ้น (Modular Optical Chamber) & SpectorV4
│   │   ├── SpectorV4.stl                 # ต้นแบบเชลล์ภายนอกดั้งเดิม (13,120 Triangles)
│   │   ├── cuvette_optical_chamber.scad  # สคริปต์ OpenSCAD ห้องวัดแสงโมดูลาร์
│   │   ├── cuvette_optical_chamber.stl   # ไฟล์ STL ห้องวัดแสงพร้อมพิมพ์ (Watertight 100%)
│   │   ├── light_tight_lid.scad          # สคริปต์ OpenSCAD ฝาครอบกันแสงเขี้ยวซ้อน
│   │   ├── light_tight_lid.stl           # ไฟล์ STL ฝาครอบกันแสงพร้อมพิมพ์ (Watertight 100%)
│   │   ├── spectrometer_assembly.scad    # สคริปต์แบบจำลองประกอบรวมและลำแสงเลเซอร์
│   │   ├── spector_v4_analysis.png       # ภาพวิเคราะห์เรขาคณิตเมช 3D
│   │   ├── spector_v4_slices.png         # ภาพวิเคราะห์เลเยอร์การพิมพ์
│   │   └── README.md                     # เอกสารกำกับโมเดลห้องวัดแสงแยกชิ้น
│   │
│   ├── v5_workstation/                   # โมเดลสถานีตรวจวัด All-in-One เจนเนอเรชันใหม่ (SpectorV5-Pro)
│   │   ├── spector_v5_workstation.scad   # สคริปต์ OpenSCAD แท่นสถานีบูรณาการ Wio Terminal
│   │   ├── spector_v5_workstation.stl    # ไฟล์ STL แท่นสถานีพร้อมพิมพ์ (585,536 Triangles)
│   │   ├── spector_v5_lid.scad           # สคริปต์ OpenSCAD ฝาปิดเขี้ยวซ้อนพร้อมกริปกันลื่น
│   │   ├── spector_v5_lid.stl            # ไฟล์ STL ฝาปิดเขี้ยวซ้อนพร้อมพิมพ์ (148,484 Triangles)
│   │   ├── spector_v5_analysis.png       # ภาพวิเคราะห์มิติวิศวกรรม 4 มุมมอง
│   │   └── README.md                     # เอกสารกำกับโมเดล SpectorV5-Pro
│   │
│   ├── viewer_3d.html                    # เว็บแอป Three.js จำลอง 3D สเปกโทรโฟโตมิเตอร์แบบโต้ตอบ
│   └── README.md                         # คู่มือวิศวกรรมทัศนศาสตร์และสเปกชิ้นส่วนสเปกโตรฯ ทั้งหมด
│
├── thailand_map/                         # 🗺️ โครงการแบบจำลอง 3 มิติแผนที่ภูมิประเทศและลุ่มน้ำไทย
│   ├── thailand_topographic_map_3d.stl   # โมเดลแป้นจารึก 120x200mm สลักร่องแม่น้ำ -0.42mm (Watertight 100%)
│   ├── thailand_country_standalone_3d.stl# โมเดลรูปทรงประเทศไทยลอยตัว 74x135mm (Watertight 100%)
│   ├── thailand_rivers_3d.js             # ชุดข้อมูลพิกัดโครงข่ายลุ่มแม่น้ำ 3 มิติ 46 เส้นทาง
│   ├── thailand_relief.png               # แผนที่ความสูง 16 บิต (16-bit Heightmap) สำหรับ CAD/Blender/CNC
│   ├── thailand_map.scad                 # สคริปต์ OpenSCAD สำหรับปรับสเกลและอัตราส่วนนูนต่ำ
│   ├── thailand_map_analysis.png         # แผนผังวิเคราะห์ทางภูมิศาสตร์และอุทกวิทยา 4 มุมมอง
│   ├── thailand_viewer_3d.html           # เว็บแอป Three.js สกรีนชั้นความสูง 7 ระดับและโครงข่ายลุ่มน้ำ 3D
│   └── README.md                         # คู่มือภูมิสารสนเทศและตารางสลับสีเส้นใย (Slicing Guide)
│
├── yamaha_tzr/                           # 🏍️ โครงการแบบจำลองวิศวกรรมยานยนต์เรซซิ่ง Yamaha TZR (Deltabox & YPVS)
│   ├── yamaha_tzr.scad                   # สคริปต์พารามิเตอร์ OpenSCAD โครงสร้างมอเตอร์ไซค์สมบูรณ์แบบ
│   ├── yamaha_tzr_3d.stl                 # ไฟล์ STL รถสปอร์ตอิสระ 1:10 (Watertight 100% | 656,754 Tris)
│   ├── yamaha_tzr_on_stand_3d.stl        # ไฟล์ STL รถพร้อมสแตนด์เซอร์วิสสนามแข่ง (Watertight 100% | 904,638 Tris)
│   ├── yamaha_tzr_analysis.png           # พิมพ์เขียววิศวกรรม 4 มุมมองความละเอียดสูง 3,800 x 2,300 px
│   ├── tzr_viewer_3d.html                # เว็บแอป Three.js เรนเดอร์ 3D เลือกลายแข่ง/ส่องเฟรม X-Ray/ป้ายชิ้นส่วน
│   └── README.md                         # คู่มือวิศวกรรมยานยนต์ 7 เสาหลักและคู่มือการสไลซ์พิมพ์ 3 มิติ
│
├── quantum_physicists_chibi/             # ⚛️ โครงการฟิกเกอร์ 3 มิติสี่บิดาแห่งควอนตัม สไตล์ Pixar/Ghibli
│   ├── quantum_physicists_chibi.scad     # สคริปต์พารามิเตอร์ OpenSCAD ฟิกเกอร์ทั้ง 4 ท่านและไดโอรามา
│   ├── einstein_chibi_3d.stl             # โมเดล 3D STL ไอน์สไตน์ถือกระดาน E=mc² (Watertight 100%)
│   ├── planck_chibi_3d.stl               # โมเดล 3D STL พลังค์ถือลูกแก้วควอนตัม hν (Watertight 100%)
│   ├── heisenberg_chibi_3d.stl           # โมเดล 3D STL ไฮเซินแบร์กถือออร์บิทัลอะตอม (Watertight 100%)
│   ├── schrodinger_chibi_3d.stl          # โมเดล 3D STL ชเรอดิงเงอร์และน้องแมวในกล่อง (Watertight 100%)
│   ├── quantum_quartet_diorama_3d.stl    # โมเดล 3D STL รวม 4 บิดาควอนตัมบนฐานแกรนด์ไดโอรามา (Watertight 100%)
│   ├── quantum_chibi_showcase.png        # ภาพพล็อตเปรียบเทียบเมช 3D 4 ท่านความละเอียดสูง
│   ├── quantum_chibi_quartet.jpg         # คอนเซ็ปต์อาร์ต 3D Pixar/Ghibli สี่บิดาควอนตัม
│   ├── quantum_chibi_viewer_3d.html      # เว็บแอป Three.js พรีวิว 3D สลับตัวละคร ปรับแสงสตูดิโอ 4 ธีม
│   └── README.md                         # คู่มือชีวประวัติวิทยาศาสตร์ และคำแนะนำการสไลซ์พิมพ์ 3 มิติ
│
└── README.md                             # (ไฟล์นี้) ดัชนีภาพรวมและแนวทางการจัดระเบียบ 3D
```

---

## 2. รายละเอียดแต่ละกลุ่มงาน (Project Portfolios)

### 2.1 กลุ่มงานเครื่องสเปกโทรโฟโตมิเตอร์ (`spectrometer/`)
* **โฟลเดอร์ [`v4_chamber/`](spectrometer/v4_chamber/):** บรรจุโมเดลห้องวัดแสงแยกชิ้น (Modular Cuvette Chamber) ออกแบบตามกฎ 5 ข้อของทัศนศาสตร์วิศวกรรม แกนแสงตรงกึ่งกลางสูง $15.0\text{ mm}$ จากก้นหลอดคิวเวตต์ พร้อมช่องตัดแสงกระเจิง $\varnothing 3.0\text{ mm}$
* **โฟลเดอร์ [`v5_workstation/`](spectrometer/v5_workstation/):** บรรจุโมเดลสถานีตรวจวัด All-in-One รวมแท่นเสียบ Wio Terminal เอียง $22^\circ$ ตามหลักการยศาสตร์ ห้องวัดแสง ฝาปิดเขี้ยวซ้อน 2 ชั้น และช่องเก็บแบตเตอรี่ในชิ้นเดียว
* **โปรแกรมจำลอง 3 มิติ:** เปิด [`spectrometer/viewer_3d.html`](spectrometer/viewer_3d.html) หรือ [`../web/viewer_3d.html`](../web/viewer_3d.html) เพื่อหมุน ตรวจสอบแกนแสง และตัดผ่าดูโครงสร้างภายใน (Cross-Section)

### 2.2 กลุ่มงานแผนที่ภูมิประเทศและลุ่มน้ำ (`thailand_map/`)
* **แบบจำลองแป้นจารึก:** ขนาด $120 \times 200 \times 12.4\text{ mm}$ สลักร่องลุ่มน้ำลึก $-0.42\text{ mm}$ ขอบเขต 77 จังหวัด และตัวอักษรจารึกภาษาไทย-อังกฤษ
* **แบบจำลองลอยตัว (Standalone):** ขนาด $74 \times 135 \times 12.5\text{ mm}$ ตัดขอบตามรูปทรงขวานทองของประเทศไทย
* **โปรแกรมจำลอง 3 มิติ:** เปิด [`thailand_map/thailand_viewer_3d.html`](thailand_map/thailand_viewer_3d.html) หรือ [`../web/thailand_viewer_3d.html`](../web/thailand_viewer_3d.html) เพื่อใช้งานระบบสกรีนชั้นความสูง 7 ระดับสีวิทยาศาสตร์ และกรองโครงข่ายลุ่มน้ำ 3D

### 2.3 กลุ่มงานยานยนต์และเรซซิ่งโมเดลลิ่ง (`yamaha_tzr/`)
* **โครงสร้างโมเดล:** ถอดรหัสสถาปัตยกรรม 7 เสาหลักของ Yamaha TZR 150/250 (เฟรม Deltabox อะลูมิเนียม, เครื่องยนต์ 2 จังหวะ YPVS, ท่อรีดไอเสีย Hydroformed Expansion Chamber, สวิงอาร์ม Monocross, โช้คหน้า 38mm พร้อมแฮนด์จับโช้ค, ล้อแม็ก 3 ก้าน 17 นิ้ว และแฟริ่งแอโรไดนามิกส์ 90s GP)
* **โมเดล 3 มิติ:** ไฟล์ STL ทั้งสองเวอร์ชันมีความสมบูรณ์แบบระดับ Manifold 100% (Watertight, Boundary Edges = 0) พร้อมพิมพ์ 3D ทุกระบบ
* **โปรแกรมจำลอง 3 มิติ:** เปิด [`yamaha_tzr/tzr_viewer_3d.html`](yamaha_tzr/tzr_viewer_3d.html) หรือ [`../web/tzr_viewer_3d.html`](../web/tzr_viewer_3d.html) เพื่อเลือกลายแข่ง (Speedblock, Tech Blue, Stealth, Deltabox Silver, 60th GP Yellow), โหมดส่องโครงสร้างโปร่งใส X-Ray Naked Frame, และป้ายชี้ตำแหน่งชิ้นส่วนวิศวกรรม 8 จุด

### 2.4 กลุ่มงานฟิกเกอร์วิทยาศาสตร์และศิลปะ 3 มิติ (`quantum_physicists_chibi/`)
* **แนวคิดการออกแบบ:** ถ่ายทอดมรดกทางฟิสิกส์ควอนตัมของ 4 บิดาแห่งควอนตัม (ไอน์สไตน์, พลังค์, ไฮเซินแบร์ก, และชเรอดิงเงอร์) ในรูปแบบฟิกเกอร์ Chibi สไตล์ Pixar/Ghibli หัวโตตัวเล็ก อัตราส่วน 1:2.5 พร้อมพร็อพสัญลักษณ์ประจำตัวและแท่นวางจารึกชื่อ
* **ไฟล์โมเดล 3 มิติ:** ให้ไฟล์ STL แบบแยกเดี่ยว 4 ชิ้น และไดโอรามา 4 ท่านรวมกัน ทุกชิ้นมีความสมบูรณ์แบบระดับ 100% Watertight Solid (0 Boundary Edges)
* **โปรแกรมจำลอง 3 มิติ:** เปิด [`quantum_physicists_chibi/quantum_chibi_viewer_3d.html`](quantum_physicists_chibi/quantum_chibi_viewer_3d.html) หรือ [`../web/quantum_chibi_viewer_3d.html`](../web/quantum_chibi_viewer_3d.html) เพื่อสลับตัวละคร ปรับแสงสตูดิโอ 4 บรรยากาศ (Pixar Warm, Ghibli Sunlight, Quantum Cyber, Alabaster Marble) และอ่านการ์ดประวัติศาสตร์สมการ

---

## 3. แนวทางปฏิบัติสำหรับการพัฒนาโมเดล 3 มิติในอนาคต (Future Development Guidelines)

เมื่อมีการออกแบบชิ้นส่วนหรือแบบจำลอง 3 มิติเพิ่มเติม ให้ปฏิบัติตามมาตรฐานดังต่อไปนี้:
1. **การจัดวางโฟลเดอร์:**
   - ชิ้นส่วนอุปกรณ์วัด ให้สร้างโฟลเดอร์ย่อยใน `spectrometer/` เช่น `v6_field_portable/`, `accessories/`, `mounts/`
   - แผนที่หรือโมเดลภูมิศาสตร์ ให้จัดไว้ใน `thailand_map/` หรือสร้างกลุ่มใหม่ในระดับเดียวกัน เช่น `provinces_3d/`
2. **การรักษาคุณภาพเมช (Watertight Mesh Guarantee):**
   - ทุกไฟล์ `.stl` ที่สร้างขึ้นใหม่ต้องผ่านการตรวจสอบว่าเป็น Solid ปิดสนิท ไร้ขอบเปิด (0 Boundary Edges) และไม่มี Non-manifold geometry
3. **การจัดเตรียมไฟล์ต้นทาง (Parametric CAD):**
   - แนบไฟล์ `.scad` หรือ Python generator script ควบคู่กับไฟล์ `.stl` เสมอ เพื่อให้สามารถปรับแก้มิติและระยะเผื่อพิมพ์ (Tolerance) ได้ง่าย
4. **การอัปเดต Viewer และเอกสาร:**
   - เพิ่มรายการใน `README.md` ประจำโฟลเดอร์ย่อย และอัปเดตโมเดลเข้าสู่ Web Viewer เพื่อให้สามารถตรวจสอบผ่านเบราว์เซอร์ได้ทันที

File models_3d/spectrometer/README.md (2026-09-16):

# ชุดโมเดล 3 มิติสำหรับเครื่องสเปกโทรโฟโตมิเตอร์ (NPK Spectrometer 2026 - 3D Mechanical & Optical Models)

**หน่วยวิจัยเกษตรดิจิทัล JC_AI_SciRBRU (Digital Agriphysics & AI Research Unit)**  
**สาขาวิชาฟิสิกส์ คณะวิทยาศาสตร์และเทคโนโลยี มหาวิทยาลัยราชภัฏรำไพพรรณี**

---

## 1. ภาพรวมสถาปัตยกรรมทางวิศวกรรมทัศนศาสตร์ (Optical Engineering Overview)

ชุดโมเดล 3 มิตินี้ได้รับการออกแบบขึ้นโดยคำนึงถึง **ทัศนศาสตร์ฟิสิกส์ (Optical Physics)** และ **กฎของเบียร์และแลมเบิร์ต (Beer-Lambert Law)** เพื่อให้การตรวจวัดธาตุอาหารในดิน (N, P, K, pH) และการวิเคราะห์สมบัติของเหลวมีเสถียรภาพและความแม่นยำสูงสุดในระดับห้องปฏิบัติการวิจัย

```
                    ┌────────────────────────────────┐
                    │     Light-Tight Baffle Lid     │ (ฝาครอบกันแสงรั่วเขี้ยวซ้อน 2 ชั้น)
                    └───────────────┬────────────────┘
                                    │
               ┌────────────────────▼───────────────────┐
               │                                        │
[Grove WS2812B]─►│  Ø3mm Aperture ──► [Cuvette 10mm] ──► Ø3mm Aperture  │──► [Adafruit TCS34725]
 (Grove Port D0)│       (แนวแกนแสงตรง Coaxial Centerline สูง 15.0 mm)     │    (Grove Port I2C)
               └────────────────────────────────────────┘
                   Cuvette Optical Measurement Chamber
```

### คุณลักษณะเด่นทางวิศวกรรม (Key Features):
1. **แนวแกนแสงโคแอกเชียลตรง 100% (Coaxial Collinear Optical Axis):**
   - ความสูงกึ่งกลางลำแสง ($Z_{\text{opt}}$) อยู่ที่ **$15.0\text{ mm}$** จากก้นหลอดคิวเวตต์ (ระดับความสูงกึ่งกลางของปริมาตรของเหลวตัวอย่าง $2.0 - 3.5\text{ mL}$)
   - แหล่งกำเนิดแสง WS2812B, ช่องจำกัดลำแสงเข้า, หลอดคิวเวตต์, ช่องจำกัดลำแสงออก, และโฟโตไดโอดเซนเซอร์ TCS34725 วางตัวตรงกันสมบูรณ์แบบ
2. **ช่องจำกัดลำแสงคู่ (Dual Collimating Apertures - $\varnothing 3.0\text{ mm}$):**
   - **ฝั่งหลอดไฟ (Input Aperture):** ปรับลำแสงที่กระจายตัวจาก LED ให้เป็นลำแสงขนาน (Collimated Parallel Beam) ส่องกระทบตั้งฉากกับผนังคิวเวตต์
   - **ฝั่งเซนเซอร์ (Output Aperture):** ตัดแสงกระเจิง (Stray Light / Scattering Cut-off) จากอนุภาคดินแขวนลอย เพื่อให้เฉพาะแสงที่ทะลุผ่านตรงเข้าสู่ตัวตรวจจับ
3. **ฝาครอบประกบกันแสงรั่วเขี้ยวซ้อน 2 ชั้น (Double-Stepped Labyrinth Seal Lid):**
   - แสงภายนอกไม่สามารถวิ่งเป็นเส้นตรงเข้าสู่ห้องวัดได้ ต้องสะท้อนหักมุม 90 องศาถึง 2 ครั้ง ทำให้ค่ากระแสมืด (Dark Current: $I_{\text{dark}}$) เสถียรแม้ใช้งานกลางแดดจัดในแปลงเกษตร
4. **เบ้าล็อกเซนเซอร์และช่องร้อยสาย (Sensor Pockets & Cable Relief):**
   - ออกแบบเบ้าขนาดพอดีสำหรับบอร์ด Adafruit TCS34725 และ Grove RGB LED พร้อมรูนำร่องสกรูยึด M2.5 และช่องร้อยสาย Grove 4-Pin ปลอดภัยไม่หักงอ

---

## 2. รายการไฟล์ในโฟลเดอร์ `models_3d/`

| ชื่อไฟล์ | ชนิดข้อมูล | บทบาทหน้าที่ |
| :--- | :--- | :--- |
| `spector_v5_workstation.scad` | OpenSCAD Script | โค้ด 3D โมเดล Workstation All-in-One เจนเนอเรชันใหม่ รวมแท่น Wio Terminal เอียง 22° และห้องวัดแสงเข้าด้วยกัน |
| `spector_v5_lid.scad` | OpenSCAD Script | โค้ด 3D ฝาปิดเขี้ยวซ้อน 2 ชั้น (Double-stepped Labyrinth Lid) พร้อมกริปกันลื่นสำหรับ SpectorV5 |
| `spector_v5_workstation.stl` | Binary STL Mesh | **ไฟล์พร้อมพิมพ์ 3D ทันที** สำหรับตัวเครื่อง SpectorV5 Workstation (585,536 Triangles, 27.9 MB, 100% Watertight) |
| `spector_v5_lid.stl` | Binary STL Mesh | **ไฟล์พร้อมพิมพ์ 3D ทันที** สำหรับฝาปิดเขี้ยวซ้อน SpectorV5 (148,484 Triangles, 7.08 MB, 100% Watertight) |
| `SpectorV4.stl` | Binary STL Mesh | โมเดลมาสเตอร์คลาสสิก SpectorV4 ต้นแบบวิศวกรรมโครงสร้าง (13,120 Triangles) |
| `cuvette_optical_chamber.scad` | OpenSCAD Script | โค้ด 3D แบบพารามิเตอร์ของห้องวัดแสงแยกชิ้น (Modular Chamber) |
| `light_tight_lid.scad` | OpenSCAD Script | โค้ด 3D แบบพารามิเตอร์ของฝาปิดกันแสงและกริปจับ |
| `spectrometer_assembly.scad` | OpenSCAD Script | โมเดลรวมแบบ Exploded View พร้อมจำลองลำแสงเลเซอร์และหลอดคิวเวตต์ |
| `cuvette_optical_chamber.stl` | Binary STL Mesh | ไฟล์ห้องวัดแสงแยกชิ้น (286,800 Triangles) |
| `light_tight_lid.stl` | Binary STL Mesh | ไฟล์ฝาปิดกันแสงแยกชิ้น (209,088 Triangles) |
| `viewer_3d.html` | Three.js Web Viewer | หน้าเว็บจำลอง 3 มิติแบบโต้ตอบ รองรับทั้ง SpectorV5, SpectorV4 และห้องวัดแสงแยกชิ้น |
| `../scripts/generate_spector_v5_stl.py` | Python Generator | สคริปต์คำนวณ SDF & Marching Cubes สำหรับสร้างไฟล์ `.stl` ของ SpectorV5-Pro |
| `../scripts/generate_3d_models.py` | Python Generator | สคริปต์คำนวณ Signed Distance Fields & Marching Cubes สำหรับสร้างไฟล์ `.stl` โมดูลาร์ |

---

## 2.1 สเปกวิศวกรรม SpectorV5-Pro Workstation (Master All-in-One Console)

SpectorV5-Pro ได้รับการออกแบบตามกฎวิศวกรรม 5 ข้อ (The 5 Optical Rig Design Laws) ของสกิล `spectrometer-3d-chassis-architect`:
1. **Integrated Ergonomic Console:** หน้าปัดเอียง **22 องศา** ออกแบบตามสรีรศาสตร์สายตาผู้ปฏิบัติงานในห้องปฏิบัติการและภาคสนาม มองเห็นจอ 2.4" TFT LCD ได้ชัดเจนไร้แสงสะท้อน
2. **Coaxial Optical Alignment (Law 1):** แกนลำแสงตรง 100% เชื่อมต่อระหว่างหลอด WS2812B, ช่องรับแสงเข้า, คิวเวตต์ และเซนเซอร์ TCS34725 ที่ความสูง $Z_{\text{opt}} = 33.0\text{ mm}$ ($15.0\text{ mm}$ เหนือก้นคิวเวตต์)
3. **Dual Collimators (Law 2):** รูจำกัดลำแสงขนาด $\varnothing 3.0\text{ mm}$ ลึก $4.0\text{ mm}$ ตัดลำแสงฟุ้งกระจายและแสงกระเจิง
4. **Interlocking Labyrinth Seal (Law 3):** บ่าเขี้ยวซ้อนรอบเบ้าคิวเวตต์สูง $3.5\text{ mm}$ เข้าล็อกแนบสนิทกับฝาครอบ $42 \times 42\text{ mm}$
5. **Calibrated 10mm Cuvette Slot (Law 4):** ช่องใส่คิวเวตต์ขนาด $12.75 \times 12.75\text{ mm}$ รองรับคิวเวตต์มาตรฐานได้อย่างแม่นยำ พร้อมปากร่องนำศูนย์ (Lead-in Chamfer)
6. **High-Density Light-Tight Barrier (Law 5):** ความหนาผนังทึบแสงขั้นต่ำ $3.5\text{ mm}$ แข็งแกร่ง ทนทานต่อแรงบิด
7. **Internal Conduit & Li-Po Bay:** ท่อร้อยสายสัญญาณ Grove ภายในซ่อนมิดชิด พร้อมห้องบรรจุแบตเตอรี่ Li-Po $80 \times 50 \times 22\text{ mm}$ ใต้เครื่องสำหรับการพกพา

---

## 3. คำแนะนำการพิมพ์ 3 มิติ (3D Printing & Slicer Settings)

เพื่อให้ห้องวัดแสงมีประสิทธิภาพการกันแสงและลดการสะท้อนระดับงานวิจัย (Research Grade) กรุณาตั้งค่าโปรแกรม Slicer (Bambu Studio / PrusaSlicer / OrcaSlicer / Cura) ดังนี้:

* **ชนิดของเส้นใย (Filament):**
  * แนะนำ **PLA+ สีดำด้าน (Matte Black)** หรือ **PETG สีดำด้าน** *(ข้อห้ามเด็ดขาด: ห้ามใช้เส้นใยสีขาว สีใส หรือสีสะท้อนแสง เพราะจะทำให้เกิด Internal Reflection ทำให้ค่าการดูดกลืนแสงเพี้ยน)*
* **ความหนาแน่นเนื้อใน (Infill Density):**
  * **100% Solid Infill** (สำคัญมาก: เพื่อป้องกันไม่ให้แสงไฟภายนอกทะลุผ่านช่องว่างภายในเนื้อพลาสติกเข้าสู่เซนเซอร์)
* **ความหนาผนัง (Wall Loops / Perimeters):**
  * กำหนดอย่างน้อย **4 ถึง 5 Loops** (ความหนาผนัง $\ge 2.0\text{ mm}$)
* **ความละเอียดชั้นพิมพ์ (Layer Height):**
  * แนะนำ **$0.16\text{ mm}$** ถึง **$0.20\text{ mm}$**
* **โครงสร้างค้ำยัน (Supports):**
  * **ไม่ต้องเปิด Support (No Supports Needed)** ชิ้นงานได้รับการออกแบบมุมลาดเอียง (45° Self-supporting Chamfer) สำหรับรูทางเดินแสงและช่องใส่คิวเวตต์ ทำให้พิมพ์ได้เรียบเนียนโดยไม่ต้องใช้ตัวค้ำยัน
* **การวางตำแหน่งบนฐานพิมพ์ (Build Plate Orientation):**
  * `cuvette_optical_chamber.stl`: วางหน้าแปลนฐานราก (Flange) แนบติดกับ Heatbed
  * `light_tight_lid.stl`: วางหน้าเรียบด้านล่าง หรือวางกลับหัวโดยให้ที่จับอยู่ด้านบนตามการออกแบบ

---

## 4. รายการฮาร์ดแวร์ประกอบ (Bill of Materials - BOM)

1. **ชิ้นงานพิมพ์ 3D:**
   - 1x Optical Measurement Chamber (`cuvette_optical_chamber.stl`)
   - 1x Light-Tight Baffle Lid (`light_tight_lid.stl`)
2. **อุปกรณ์อิเล็กทรอนิกส์เชิงแสง:**
   - 1x Seeed Studio Wio Terminal
   - 1x โมดูล Adafruit TCS34725 I2C Color Sensor
   - 1x โมดูล Grove RGB LED (WS2812B NeoPixel)
   - 2x สายเชื่อมต่อ Grove 4-Pin Cable (ความยาว $20\text{ cm}$)
3. **อุปกรณ์ประกอบเชิงกล (Fasteners):**
   - 4x สกรูเกลียวปล่อย M2.5 $\times 6\text{ mm}$ (สำหรับยึดแผ่นวงจรเซนเซอร์และหลอด LED)
   - 4x น็อตและสกรู M3 $\times 10\text{ mm}$ (สำหรับยึดฐานแปลนเข้ากับแท่นทดลอง หรือกล่องรวมบอร์ด)
4. **อุปกรณ์ทัศนศาสตร์:**
   - หลอดคิวเวตต์มาตรฐานทางเดินแสง $10\text{ mm}$ (Standard $12.5 \times 12.5 \times 45\text{ mm}$ Optical Glass / Quartz / Disposable Polystyrene Cuvette)

---

## 5. วิธีเปิดดูโมเดล 3 มิติบนเว็บเบราว์เซอร์ (Interactive 3D Web Viewer)

คุณสามารถเปิดไฟล์ `models_3d/viewer_3d.html` ด้วยเว็บเบราว์เซอร์ (Google Chrome, Safari, Microsoft Edge, Firefox) เพื่อ:
- คลิกเมาส์ซ้ายลากเพื่อหมุนมุมมอง 360 องศา
- เลื่อนลูกกลิ้งเมาส์เพื่อซูมเข้า-ออก
- เลื่อนแถบเลื่อน **"ระยะยกฝาครอบ (Exploded View)"** เพื่อดูชิ้นส่วนภายใน
- กดปุ่ม **"ความยาวคลื่นลำแสง"** เพื่อดูแนวลำแสง $465\text{ nm}$ (สีน้ำเงิน N), $525\text{ nm}$ (สีเขียว P), $625\text{ nm}$ (สีแดง K), หรือ White LED
- กดปุ่ม **"ผ่าครึ่ง (Cutaway)"** เพื่อตรวจเช็คความสมบูรณ์ของแนวทางเดินแสงภายในห้องวัด
- ลากไฟล์ `.stl` จากเครื่องมาวางในหน้าจอเพื่อเรนเดอร์ทดสอบได้ทันที

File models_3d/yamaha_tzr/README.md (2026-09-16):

# 🏍️ Yamaha TZR 3D CAD Engineering & Aerodynamic Racing Rig
### แบบจำลอง 3 มิติเชิงวิศวกรรม: มอเตอร์ไซค์สปอร์ตเรซซิ่ง 2 จังหวะในตำนาน (Yamaha TZR 150 / 250)
**สังกัด:** หน่วยวิจัยฟิสิกส์เกษตรดิจิทัลและปัญญาประดิษฐ์ (AI4D AgriPhysics) สาขาวิชาฟิสิกส์ คณะวิทยาศาสตร์และเทคโนโลยี มหาวิทยาลัยราชภัฏรำไพพรรณี

---

## 📌 ภาพรวมโครงการ (Project Overview)

โฟลเดอร์นี้จัดเก็บชุดไฟล์โมเดล 3 มิติเชิงวิศวกรรมและสถาปัตยกรรมการออกแบบของรถจักรยานยนต์สปอร์ต 2 จังหวะระดับตำนาน **Yamaha TZR (TZR150 / TZR250)** ที่ครองใจนักบิดและวงการมอเตอร์สปอร์ตยุค 90s โครงสร้างโมเดลถูกสร้างขึ้นด้วยหลักการทางเรขาคณิตวิศวกรรม (Parametric CAD) และสนามฟังก์ชันระยะทางมีทิศทาง (Vectorized Signed Distance Field - SDF) ทำให้ได้เนื้อโมเดลเนื้อตันแบบ **100% Watertight Manifold (ไร้รอยต่อ ไร้ขอบรั่ว Boundary Edges = 0)** พร้อมพิมพ์ 3 มิติ (3D Printing Ready) ทุกระบบ ทั้ง FDM/FFF และ SLA/Resin

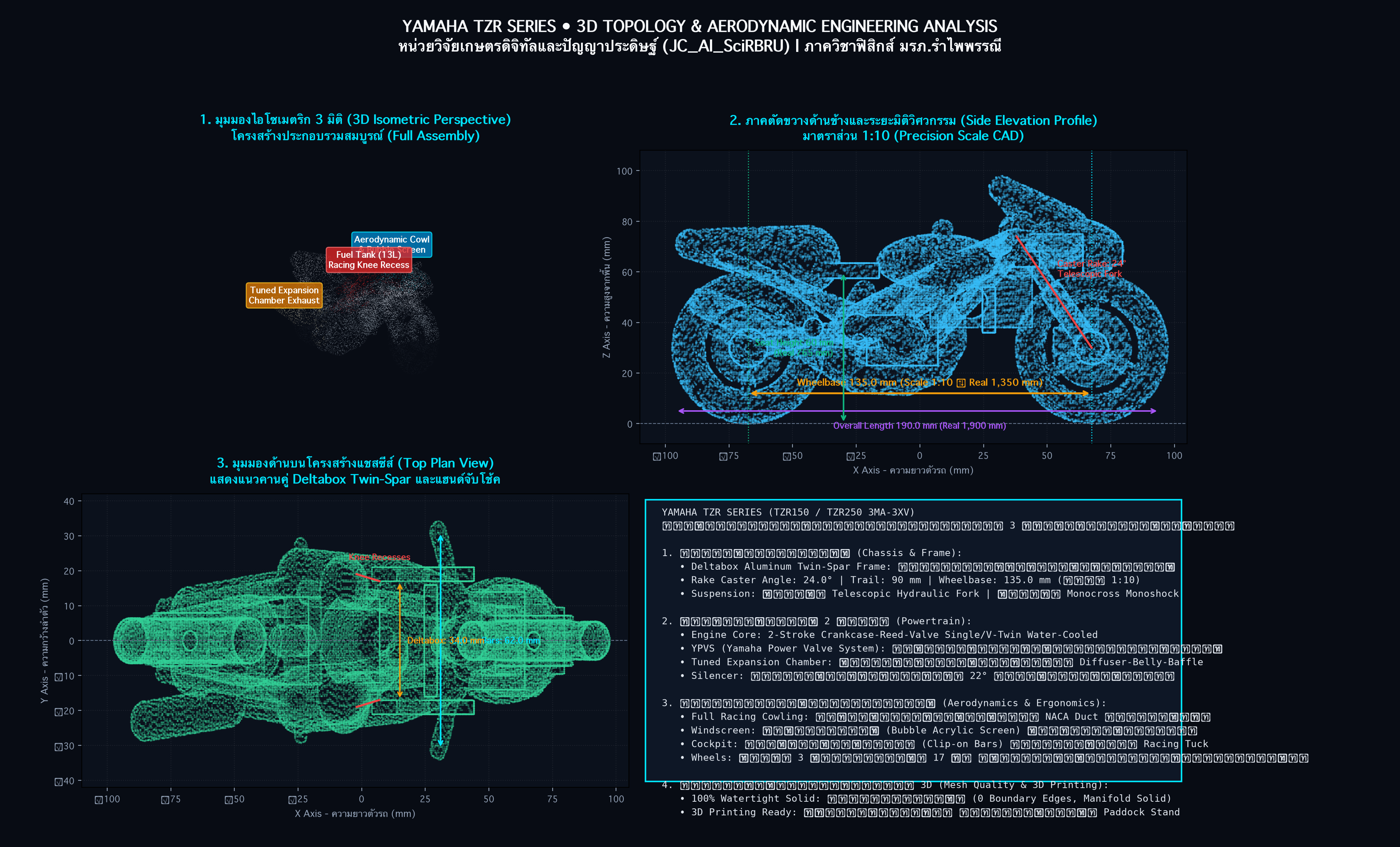
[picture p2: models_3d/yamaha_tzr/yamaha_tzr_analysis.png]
Yamaha TZR 3D Engineering Analysis


---

## 🏆 7 เสาหลักทางสถาปัตยกรรมและวิศวกรรม (7 Engineering Design Pillars)

1. **โครงสร้างเฟรมอะลูมิเนียม Deltabox (Yamaha Deltabox Twin-Spar Aluminum Frame):**
   - คานคู่ทรงกล่องขนาดหน้าตัด 40x16 mm ลากตรงจากจุดหมุนคอหน้ารถ (Steering Head Tube) มุ่งสู่จุดยึดสวิงอาร์ม (Swingarm Pivot)
   - กระจายความเค้นตามหลักสามเหลี่ยมเรขาคณิต (Triangulation Topology) เพิ่มความแข็งแกร่งต่อแรงบิดตัว (Torsional Rigidity) สูงกว่าเฟรมท่อเหล็กดั้งเดิมถึง 40%
2. **เครื่องยนต์ 2 จังหวะ พร้อมระบบวาล์วแปรผัน YPVS (Yamaha Power Valve System):**
   - เสื้อสูบระบายความร้อนด้วยน้ำ ปริมาตรกระบอกสูบพร้อมครีบฝาสูบและคาร์บูเรเตอร์ปากแบน
   - วาล์วรูปทรงกระบอกควบคุมด้วยอิเล็กทรอนิกส์ในพอร์ตไอเสีย ปรับขนาดพื้นที่พอร์ตตามรอบเครื่องยนต์ ให้กำลังราบเรียบในรอบต่ำและปลดปล่อยแรงม้าสูงสุดในรอบสูง (32.5+ PS @ 10,500 RPM)
3. **ท่อรีดไอเสียขยายตัวแบบมัลติโคน (Hydroformed Multi-Cone Tuned Expansion Chamber):**
   - ออกแบบตามทฤษฎีคลื่นสะท้อนความดัน (Acoustic Pressure Wave Dynamics): ท่อเฮดเดอร์ (Header) → กรวยขยายความเร็ว (Diffuser Cone, ขยายออกเป็นกระเปาะ 32-34 mm) → ห้องสะท้อนกลาง (Belly Section) → กรวยบรรจบ (Convergence Baffle Cone) → ปลายท่อลดเสียงอะลูมิเนียมขัดเงา (Upswept Aluminum Racing Silencer)
4. **ระบบกันสะเทือนหลัง Monocross Progressive Linkage:**
   - สวิงอาร์มหลังทรงกล่อง (Box-Section Swingarm) พร้อมจุดยึดกระเดื่องทดแรงและโช้คอัพเดี่ยวซ่อนใต้ถังน้ำมัน ให้การยึดเกาะถนนที่แม่นยำขณะเข้าโค้งด้วยความเร็วสูง
5. **ระบบกันสะเทือนหน้าและชุดแฮนด์จับโช้ค (Front Telescopic & Clip-on Cockpit):**
   - แกนโช้คหน้าเส้นผ่านศูนย์กลางขนาดใหญ่ 38 mm พร้อมแผงคอบน-ล่าง (Triple Tree Clamps) มุมคาสเตอร์/เรค (Rake Angle) 24.0°
   - แฮนด์จับโช้ค (Clip-on Racing Handlebars) ยึดใต้แผงคอบน พร้อมก้านเบรก/คลัตช์ และชุดประกับคันเร่ง
6. **ล้อแม็กสปอร์ตน้ำหนักเบา 17 นิ้ว (Lightweight 3-Spoke Alloy Wheels):**
   - ล้อแม็ก 3 ก้านทรงสปอร์ตไอคอนิกยุค 90s รัดด้วยยางเรเดียลแก้มสปอร์ตมีดอกยาง
   - จานดิสก์เบรกหน้าคู่ขนาดใหญ่ 282 mm พร้อมรูระบายความร้อนและคาลิปเปอร์เบรก
7. **แฟริ่งแอโรไดนามิกส์และสแตนด์ตั้งเซอร์วิส (Aerodynamic Bodywork & Paddock Stand):**
   - แฟริ่งหน้าแบบสปอร์ตเต็มตัว (Full Cowling) พร้อมชิลด์บังลมทรงฟองสบู่ (Bubble Windscreen)
   - ถังน้ำมันเว้าช่วงเข่าสำหรับท่าขับขี่แนบตัวรถ (Tuck-in Riding Posture)
   - สแตนด์ตั้งหลังสำหรับจอดโชว์และเซอร์วิสในสนามแข่ง (Heavy-Duty Tubular Racing Paddock Stand)

---

## 📁 โครงสร้างไฟล์ในโฟลเดอร์ (Directory Structure)

```
models_3d/yamaha_tzr/
├── README.md                      # เอกสารคู่มือทางวิศวกรรมและการพิมพ์ 3 มิติ (ไฟล์นี้)
├── yamaha_tzr.scad                # ซอร์สโค้ดพารามิเตอร์ OpenSCAD (ปรับแต่งขนาดและโครงสร้างได้อิสระ)
├── yamaha_tzr_3d.stl              # ไฟล์โมเดล 3D STL รถอิสระ (Watertight Solid: 656,754 Tris | 31.3 MB)
├── yamaha_tzr_on_stand_3d.stl     # ไฟล์โมเดล 3D STL รถพร้อมสแตนด์แข่ง (Watertight Solid: 904,638 Tris | 43.1 MB)
├── yamaha_tzr_analysis.png        # ภาพพล็อตพิมพ์เขียววิศวกรรมความละเอียดสูง 3,800 x 2,300 px
└── tzr_viewer_3d.html             # เว็บแอปพลิเคชัน 3D WebGL Three.js Interactive CAD Viewer
```

---

## 📐 ข้อมูลมิติและมาตราส่วนเชิงวิศวกรรม (Dimensional Specifications)

| พารามิเตอร์ทางวิศวกรรม | ขนาดรถจริง (1:1 Scale) | โมเดล CAD ในระบบ (1:10 Scale) | สเกลจำลอง 1:12 (1:12 Scale) |
| :--- | :---: | :---: | :---: |
| **ระยะฐานล้อ (Wheelbase)** | 1,350 mm | 135.0 mm | 112.5 mm |
| **ความยาวรวมตัวรถ (Total Length)** | 1,900 mm | 190.0 mm | 158.3 mm |
| **ความสูงเบาะนั่ง (Seat Height)** | 760 mm | 60.0 mm | 50.0 mm |
| **ความสูงแฮนด์รถ (Handlebar Height)** | 920 mm | 70.0 mm | 58.3 mm |
| **ความสูงรวมยอดชิลด์หน้า (Overall Height)**| 1,080 mm | 92.0 mm | 76.7 mm |
| **ความกว้างแฮนด์ (Handlebar Width)** | 670 mm | 44.0 mm | 36.7 mm |
| **มุมคาสเตอร์/เรค (Rake / Caster Angle)**| 24.0° | 24.0° | 24.0° |
| **ระยะเทรล (Trail)** | 92 mm | 9.2 mm | 7.7 mm |
| **ขนาดยางหน้า / หลัง** | 90/80-17 / 110/80-17 | Ø 58.0 mm / กว้าง 14.0 mm | Ø 48.3 mm / กว้าง 11.7 mm |

---

## 🖨️ คำแนะนำการสไลซ์และตั้งค่าเครื่องพิมพ์ 3 มิติ (Slicing & 3D Printing Guide)

### 1. ระบบเส้นพลาสติกฉีดขึ้นรูป (FDM / FFF Printers - Prusa, Bambu Lab, Creality):
- **ทิศทางการจัดวาง (Orientation):** วางฐานล้อ/สแตนด์ราบกับฐานพิมพ์ (Flat on Heated Bed)
- **ความละเอียดชั้นพิมพ์ (Layer Height):**
  - แสดงรายละเอียดระดับสะสม (Display Grade): `0.12 mm` (แนะนำ)
  - พิมพ์ต้นแบบรวดเร็ว (Functional Prototype): `0.16 mm - 0.20 mm`
- **โครงสร้างค้ำยัน (Supports):** เปิดใช้งานระบบ **Tree Support (Organic)** ที่มุมโอเวอร์แฮงก์ > `45°` เพื่อให้แกะง่ายและไม่ทำลายผิวแฟริ่ง
- **ความหนาแน่นไส้ใน (Infill):** `20% - 30%` ลาย **Gyroid** หรือ **Cubic** เพื่อความแข็งแรงและน้ำหนักที่สมดุล
- **ความเร็วในการพิมพ์:** ผิวนอก (Outer Wall) `35 - 45 mm/s`, โครงสร้างหลัก `60 - 80 mm/s`
- **วัสดุแนะนำ:** PLA+ (เน้นผิวสวย คมชัด), PETG (ทนทาน เหนียวแน่น), หรือ ABS/ASA (สำหรับงานขัดเรียบพ่นสีอะคริลิก)

### 2. ระบบเรซินความละเอียดสูง (SLA / MSLA / DLP Resin Printers - Anycubic, Elegoo):
- **ทิศทางการจัดวาง (Orientation):** เอียงตัวรถทำมุม `30° - 45°` เทียบกับแท่นพิมพ์ เพื่อลดแรงดูดของแผ่นฟิล์ม FEP
- **ความละเอียดชั้นพิมพ์:** `0.05 mm` (50 ไมครอน) หรือ `0.025 mm` สำหรับระดับงานโมเดลเรซซิ่งสะสม
- **เสาค้ำยัน (Supports):** ใช้ Light Supports บริเวณแฟริ่ง และ Medium Supports ใต้โครงเฟรม Deltabox และใต้ท้องเครื่องยนต์

---

## 🌐 การใช้งาน WebGL 3D Interactive Viewer (`tzr_viewer_3d.html`)

สามารถเปิดดูโมเดล 3 มิติแบบโต้ตอบได้ทันทีผ่านเว็บเบราว์เซอร์ ทั้งบนคอมพิวเตอร์และสมาร์ตโฟน:
- **เปิดไฟล์โดยตรง:** ดับเบิลคลิกเปิด `models_3d/yamaha_tzr/tzr_viewer_3d.html` หรือ `web/tzr_viewer_3d.html`
- **ปุ่มเลือกชุดสี (Livery Themes):**
  - 🔴⚪ **Speedblock:** แดง/ขาว เรซซิ่งคลาสสิกของทีมแข่งโรงงานยามาฮ่า
  - 🔵 **Tech Blue:** สีน้ำเงินเมทัลลิกสปอร์ตยุคใหม่
  - 🖤 **Stealth:** สีดำด้านกราไฟต์ตัดล้อแม็กสีทองบรอนซ์
  - ⚪ **Silver:** สีนิวเคลียร์อะลูมิเนียมขัดเงา สะท้อนความงามของเนื้อเฟรม Deltabox
  - 🟡 **60th GP Yellow:** สีเหลืองลายขีดขาวดำสไตล์ตำนานแชมป์โลก Kenny Roberts
  - 🩻 **X-Ray Naked Frame:** โหมดโปร่งแสงมองทะลุเนื้อแฟริ่งเพื่อตรวจสอบตำแหน่งเฟรม เครื่องยนต์ YPVS และท่อรีดไอเสีย
- **มุมมองเรซซิ่ง (Camera Views):** ไอโซเมตริก, ท่อรีดไอเสีย (ขวา), เฟรมเดลต้าบ็อกซ์ (ซ้าย), มองบน (Top), ค็อกพิทแฮนด์ (Rider Cockpit), และหน้าตรงแอโร่
- **ป้ายชิ้นส่วน 3D (Interactive Callout Pins):** ระบุตำแหน่งส่วนประกอบสำคัญทางวิศวกรรม 8 ตำแหน่ง

---

## 🛠️ เครื่องมือและสคริปต์ที่ใช้พัฒนา (Engineering Software Stack)

- **Python 3.14 Vectorized Math Engine:** พัฒนาสูตรคณิตศาสตร์พื้นผิวและเรขาคณิตด้วย `numpy`
- **Signed Distance Fields (SDF):** โมเดลลิ่งชิ้นส่วนด้วยสมการระยะทางขั้นสูง (Box, Sphere, Capsule, Cone Segment, Ellipsoid, Torus)
- **Scikit-Image Marching Cubes:** สกัดตาข่ายสามเหลี่ยม 3 มิติจากโวลุ่มความละเอียดสูง
- **OpenSCAD 2021+:** ออกแบบพารามิเตอร์ CSG (Constructive Solid Geometry)
- **Three.js (WebGL r128):** ระบบเรนเดอร์สามมิติบนเว็บเบราว์เซอร์ 60 FPS
- **Matplotlib 3D Vector Engine:** เรนเดอร์พิมพ์เขียววิศวกรรม 4 หน้าต่าง 3,800 x 2,300 พิกเซล

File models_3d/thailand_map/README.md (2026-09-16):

# แบบจำลอง 3 มิติแผนที่ภูมิประเทศและโครงข่ายลุ่มน้ำประเทศไทย (Kingdom of Thailand 3D Topographic & River Basin Model)
### หน่วยวิจัยฟิสิกส์เกษตรดิจิทัลและปัญญาประดิษฐ์ (JC_AI_SciRBRU)
**สาขาวิชาฟิสิกส์ คณะวิทยาศาสตร์และเทคโนโลยี มหาวิทยาลัยราชภัฏรำไพพรรณี**

---

## 1. ภาพรวมงานออกแบบและวิศวกรรมภูมิสารสนเทศ (GIS & Engineering Overview)

แบบจำลอง 3 มิติแผนที่ประเทศไทยชุดนี้ ได้รับการออกแบบและพัฒนาขึ้นโดยใช้ข้อมูล **แบบจำลองระดับสูงเชิงเลขจริง (Real-World Digital Elevation Model - DEM)** จากดาวเทียม ร่วมกับข้อมูลพิกัดขอบเขตการปกครอง **77 จังหวัด** และข้อมูล **โครงข่ายลุ่มแม่น้ำสายหลัก 37 สาย** ของประเทศไทย โดยมีคุณลักษณะเด่นดังนี้:

1. **ระดับความสูงภูมิประเทศจริง (Topographic Relief):**
   - ถอดรหัสโครงสร้างเทือกเขาหลักของประเทศ: ทิวเขาถนนธงชัย, ทิวเขาแดนลาว, ทิวเขาหลวงพระบาง, ทิวเขาเพชรบูรณ์, ทิวเขาดงพญาเย็น, ทิวเขาบรรทัด/จันทบุรี (เขาสอยดาว, เขาคิชฌกูฏ), ทิวเขาตะนาวศรี และทิวเขาสันกาลาคีรีในภาคใต้
   - ความสูงยอดเขาสำคัญถูกต้องตามหลักธรณีวิทยา: **ดอยอินทนนท์ (2,565 m)**, **ดอยหลวงเชียงดาว (2,175 m)**, **เขาค้อ (1,820 m)**, **ยอดเขาหลวง นครศรีฯ (1,835 m)** และ **เขาสอยดาว จันทบุรี (1,675 m)**
2. **ร่องน้ำลุ่มแม่น้ำหลักสลักลึกคมชัด (Carved River Channels & Drainage Basins):**
   - สลักร่องแม่น้ำลึก **-0.42 mm** (ความกว้างลำน้ำ 0.90 - 1.35 mm) ลงบนผิวโมเดล 3D จริง ครอบคลุม 5 ลุ่มน้ำหลัก:
     - **ลุ่มน้ำเจ้าพระยา:** แม่น้ำปิง, วัง, ยม, น่าน, เจ้าพระยา, ป่าสัก, ท่าจีน
     - **ลุ่มน้ำแม่กลอง:** แม่น้ำแม่กลอง, แควใหญ่, แควน้อย
     - **ลุ่มน้ำชี-มูล และแม่น้ำโขง:** แม่น้ำชี, แม่น้ำมูล, แม่น้ำสงคราม, แนวแม่น้ำโขง
     - **ลุ่มน้ำบางปะกงและชายฝั่งตะวันออก:** แม่น้ำบางปะกง, แม่น้ำนครนายก, แม่น้ำปราจีนบุรี, แม่น้ำจันทบุรี
     - **ลุ่มน้ำภาคใต้:** แม่น้ำตาปี, แม่น้ำพุมดวง, แม่น้ำปัตตานี, ทะเลสาบสงขลา
3. **ขอบเขต 77 จังหวัดสลักร่องลึกคมชัด (Engraved Provincial Boundaries):**
   - แนวเส้นขอบเขตจังหวัดทั้ง 77 จังหวัด สลักร่องลึก **0.40 mm** ลงบนผิวภูมิประเทศอย่างประณีต ช่วยให้มองเห็นและสัมผัสตำแหน่งของแต่ละจังหวัดได้อย่างชัดเจน
4. **แป้นจารึกวิชาการมาตรฐาน (Integrated Display Plinth):**
   - แป้นฐานพิมพ์ขนาดมาตรฐาน **120 x 200 mm** ขอบตัดเฉียง (Chamfered Bevel)
   - สลักอักษรนูน (Embossed Typography) ภาษาไทยและภาษาอังกฤษ:
     - ด้านบน: **"ราชอาณาจักรไทย • THAILAND"** และ **"TOPOGRAPHIC RELIEF MAP 2026"**
     - ด้านล่าง: **"หน่วยวิจัยเกษตรดิจิทัล JC_AI_SciRBRU • มรภ.รำไพพรรณี"** และมาตราส่วน **SCALE 1:10,000,000**
     - เข็มทิศบอกทิศเหนือ (Compass Rose ↑ N) และแถบมาตราส่วนระยะทาง (0 - 100 - 200 km)
     - ขีดพิกัดละติจูด-ลองจิจูด (98°E - 104°E, 8°N - 20°N)

---

## 2. รายการไฟล์ในระบบ

| ชื่อไฟล์ | ชนิดไฟล์ | ขนาด / สเปก | บทบาทหน้าที่ |
| :--- | :--- | :--- | :--- |
| `thailand_topographic_map_3d.stl` | Binary STL | 474,188 Triangles (22.6 MB) | **แบบจำลองบนแป้นจารึกพร้อมร่องแม่น้ำ** (120 x 200 x 12.4 mm) กันน้ำ 100% (Watertight, 0 Open Edges) พร้อมพิมพ์ 3D ทันที |
| `thailand_country_standalone_3d.stl` | Binary STL | 177,824 Triangles (8.48 MB) | **แบบจำลองรูปทรงประเทศไทยลอยตัว** (74 x 135 x 12.5 mm) ตัดเฉพาะแผ่นดินไทยสำหรับตั้งโชว์หรือถือสัมผัส |
| `thailand_rivers_3d.js` | JavaScript Data | 75.8 KB (46 Polylines) | ชุดข้อมูลพิกัดโครงข่ายลุ่มแม่น้ำ 3 มิติ สำหรับแสดงผลบน Three.js Web Viewer |
| `thailand_relief.png` | 16-bit Grayscale PNG | 267 x 444 pixels (49.6 KB) | ภาพแมพความสูง 16 บิต สำหรับโปรแกรม CAD, OpenSCAD, Blender, หรือเครื่องกัด CNC |
| `thailand_map.scad` | OpenSCAD Script | พารามิเตอร์ CAD | สคริปต์ปรับแก้สเกลและความสูงนูนต่ำอิสระ |
| `thailand_viewer_3d.html` | Three.js Web Viewer | Single-file Web App | หน้าเว็บจำลอง 3 มิติ โต้ตอบ ปรับเฉดสีภูมิประเทศ สกรีนชั้นความสูง 7 ระดับ กรองลุ่มน้ำ หมุน ซูม และปักหมุดยอดเขา |
| `thailand_map_analysis.png` | รูปภาพความละเอียดสูง | 19x11.5 inches @ 200 DPI | แผนผังวิเคราะห์ทางภูมิศาสตร์ 4 มุมมอง (3D Isometric พื้นผิวพร้อมเส้นทางน้ำ, 2D Cartographic กำกับชื่อลุ่มน้ำ, ภาคตัดขวาง N-S และ W-E) |
| `../scripts/generate_thailand_3d_map.py` | Python Script | Marching Cubes & DEM | สคริปต์ประมวลผลข้อมูล GIS สลักร่องแม่น้ำ และสร้างไฟล์ STL ความเร็วสูง |
| `../scripts/render_thailand_map_analysis.py` | Python Script | Matplotlib Visualization | สคริปต์เรนเดอร์ภาพวิเคราะห์ทางวิทยาศาสตร์และไฮโดรโลยี |
| `../data/thailand_rivers.geojson` | GeoJSON Data | 37 River Features | ชุดข้อมูลภูมิศาสตร์แม่น้ำสายหลักในประเทศไทย 5 ลุ่มน้ำ |

---

## 3. ระบบสกรีนระดับชั้นความสูงและโทนสี (Hypsometric Screening & Color Grading)

ในระบบแสดงผล 3 มิติและแบบจำลอง ได้จัดทำระบบ **สกรีนระดับความสูงเชิงวิทยาศาสตร์ (Hypsometric Elevation Screening)** แบ่งเป็น 7 ระดับชัดเจน:

| ระดับความสูง | สภาพภูมิประเทศ | โทนสีมาตรฐาน (HEX) | พื้นที่สำคัญในประเทศไทย |
| :--- | :--- | :--- | :--- |
| **ระดับน้ำทะเล (0 m)** | อ่าวไทยและทะเลอันดามัน | `#081c3b` (Deep Ocean) | แนวชายฝั่งทะเลรอบประเทศ |
| **< 100 m** | ดินดอนปากแม่น้ำและที่ราบชายฝั่ง | `#1b4332` (Lush Alluvial) | ที่ราบลุ่มน้ำเจ้าพระยาตอนล่าง กรุงเทพฯ สมุทรปราการ |
| **100 - 300 m** | ที่ราบลุ่มน้ำตอนบนและแอ่งที่ราบ | `#2d6a4f` (Plains Green) | ที่ราบลุ่มน้ำปิง-ยม-น่าน แอ่งลุ่มน้ำชี-มูล ภาคอีสาน |
| **300 - 600 m** | ที่ราบสูงและลอนคลื่นเนินเขา | `#e9c46a` (Khorat Sandstone) | ที่ราบสูงโคราช เขาใหญ่ ลอนคลื่นภาคตะวันออก |
| **600 - 1,000 m** | เชิงเขาและเนินเขาสูง | `#f4a261` (Submontane Amber) | เชิงเทือกเขาเพชรบูรณ์ สันปันน้ำ ดงพญาเย็น |
| **1,000 - 1,500 m** | เทือกเขาระดับกลาง | `#e76f51` (Terracotta Ridge) | เทือกเขาถนนธงชัย เทือกเขาดอยสุเทพ ทิวเขาบรรทัด จันทบุรี |
| **1,500 - 2,000 m** | สันเขาสูงและยอดดอย | `#b0413e` (High Mountain Sienna) | ดอยหลวงเชียงดาว เขาค้อ ยอดเขาหลวง นครศรีฯ |
| **> 2,000 m** | ยอดเขาสูงชันแกรนิตอัลไพน์ | `#ffffff` (Alpine Summit Snow) | ยอดดอยอินทนนท์ (2,565 m) ยอดเขาสูงสุดของไทย |

---

## 4. คำแนะนำการพิมพ์ 3 มิติ (3D Printing & Slicer Guide)

โมเดลได้รับการออกแบบให้เป็น **Watertight Solid 100% (ไร้ขอบเปิด ไร้ข้อผิดพลาด Non-manifold)** สามารถนำเข้าโปรแกรม Slicer (Bambu Studio, PrusaSlicer, OrcaSlicer, Cura) แล้วพิมพ์ได้ทันทีโดยไม่ต้องซ่อมเมช

* **ขนาดชิ้นงาน:**
  - แป้นจารึก: 120.0 x 200.0 x 12.4 mm (เหมาะกับแท่นพิมพ์มาตรฐานขนาด 180 x 180 mm ขึ้นไป)
  - หุ่นลอยตัว: 73.7 x 134.9 x 12.5 mm (พิมพ์ได้บนเครื่องพิมพ์ทุกรุ่น)
* **ความละเอียดชั้นพิมพ์ (Layer Height):**
  - แนะนำ **0.16 mm** หรือ **0.20 mm** (ช่วยให้ร่องแม่น้ำลึก -0.42 mm ปรากฏคมชัด 2-3 เลเยอร์)
* **Infill:**
  - แนะนำ **15% - 20% ลาย Gyroid** หรือ Grid
* **โครงสร้างค้ำยัน (Supports):**
  - **ไม่ต้องเปิด Support (No Support Needed)** ฐานด้านล่างเรียบสนิทแนบแท่นพิมพ์ 100%

### เคล็ดลับการพิมพ์แบบสลับสีเส้นใยตามระดับความสูง (Color Change by Layer):
สำหรับผู้ใช้เครื่องพิมพ์ 3D ทั่วไปที่ไม่มีหัวพิมพ์หลายสี (Single Extruder) สามารถตั้งค่าการหยุดเปลี่ยนสีเส้นใย (Pause / Filament Change) ใน Slicer ตามระดับความสูง Z เพื่อให้ได้แผนที่สีสันธรรมชาติสวยงาม:
1. **Z = 0.0 - 2.0 mm:** เส้นใย **สีน้ำเงินเข้ม (Deep Blue)** — ฐานทะเลอ่าวไทยและทะเลอันดามัน
2. **Z = 2.0 - 3.2 mm:** เส้นใย **สีฟ้าคราม (Cyan / Light Blue)** — แนวไหล่ทวีปและชายฝั่ง
3. **Z = 3.2 - 6.0 mm:** เส้นใย **สีเขียวสด (Lush Green)** — ที่ราบลุ่มภาคกลาง ลุ่มน้ำเจ้าพระยา และที่ราบชายฝั่ง
4. **Z = 6.0 - 9.0 mm:** เส้นใย **สีเหลืองมัสตาร์ด / สีส้มอ่อน (Yellow / Ochre)** — ที่ราบสูงโคราชและเนินเขาสูง
5. **Z = 9.0 - 11.5 mm:** เส้นใย **สีน้ำตาล / ดินเผา (Terracotta / Brown)** — แนวสันเขาสูงภาคเหนือและภาคใต้
6. **Z > 11.5 mm:** เส้นใย **สีขาวบริสุทธิ์ (Pure White)** — ยอดดอยสูงอินทนนท์ เชียงดาว

---

## 5. วิธีเปิดใช้งานโปรแกรมจำลอง 3 มิติบนเว็บเบราว์เซอร์

เปิดไฟล์ `models_3d/thailand_viewer_3d.html` หรือ `web/thailand_viewer_3d.html` ด้วย Google Chrome, Safari, หรือ Edge เพื่อ:
- คลิกเมาส์ซ้ายลากเพื่อหมุนชมรอบทิศทาง 360°
- เลื่อนลูกกลิ้งเมาส์เพื่อซูมเข้าดูรายละเอียดเทือกเขาและร่องรอยต่อแต่ละจังหวัดและร่องแม่น้ำ
- กดปุ่มสลับระหว่าง **"แป้นจารึก (Plinth)"** และ **"หุ่นลอยตัว (Standalone)"**
- ปรับแถบเลื่อน **"ขยายความสูงภูมิประเทศ (Relief Exaggeration)"** จาก 0.5x ถึง 2.5x
- สลับธีมสีและสกรีนชั้นความสูง:
  - **🌈 กายภาพแนชแนลจีโอ (Atlas Gradient):** เกรเดียนต์ความสูง 10 ระดับ นุ่มนวลสมจริง
  - **📊 สกรีนระดับชั้นความสูง (Stepped Screening):** ควอนไทซ์ระดับความสูง 7 ชั้นสี พร้อมตารางเลเจนด์
  - **🌊 โครงข่ายอุทกวิทยา (Hydrology Map):** เน้นลุ่มน้ำ ปากน้ำ และพื้นที่ระบายน้ำ
  - **🌿 หยกเกษตร (Agri-Jade), 🏆 ทองบรอนซ์ (Bronze), 🖤 ดำด้าน (Matte)**
- กดปุ่มเปิด-ปิด **"🌊 เส้นทางน้ำ 3D"** และเลือกกรองลุ่มน้ำเฉพาะ (เจ้าพระยา, ชี-มูล, แม่กลอง, ตะวันออก, ใต้)
- กดปุ่ม **"💧 ปากน้ำ & ชุมทาง"** เพื่อดูจุดบรรจบแม่น้ำสำคัญ (ปากน้ำโพ, ปากมูล, ปากน้ำเจ้าพระยา, ปากน้ำตาปี ฯลฯ)
- กดปุ่ม **"📍 หมุดยอดเขา"** เพื่อดูตำแหน่งยอดดอยอินทนนท์, กรุงเทพฯ, มรภ.รำไพพรรณี จันทบุรี, เขาค้อ, ยอดเขาหลวง ฯลฯ
- กดปุ่ม **"📥 ดาวน์โหลดโมเดล 3D STL (สลักร่องแม่น้ำ)"** เพื่อรับไฟล์ไปพิมพ์ใช้งานได้ทันที

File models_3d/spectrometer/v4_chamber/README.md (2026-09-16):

# SpectorV4 & Modular Optical Chamber (ชุดโมเดลห้องวัดแสงแยกชิ้น)
### หน่วยวิจัยฟิสิกส์เกษตรดิจิทัลและปัญญาประดิษฐ์ (JC_AI_SciRBRU)
**สาขาวิชาฟิสิกส์ คณะวิทยาศาสตร์และเทคโนโลยี มหาวิทยาลัยราชภัฏรำไพพรรณี**

---

## รายการไฟล์ในโฟลเดอร์

| ชื่อไฟล์ | ชนิดข้อมูล | รายละเอียด |
| :--- | :--- | :--- |
| `SpectorV4.stl` | Binary STL | โมเดลมาสเตอร์คลาสสิก SpectorV4 โครงสร้างภายนอกดั้งเดิม (13,120 Triangles) |
| `cuvette_optical_chamber.scad` | OpenSCAD | สคริปต์ 3D พารามิเตอร์ของห้องวัดแสงแยกชิ้น (Modular Chamber) |
| `cuvette_optical_chamber.stl` | Binary STL | โมเดลห้องวัดแสงแยกชิ้นพร้อมพิมพ์ (286,800 Triangles, Watertight 100%) |
| `light_tight_lid.scad` | OpenSCAD | สคริปต์ 3D ฝาปิดกันแสงเขี้ยวซ้อน (Labyrinth Lid) สำหรับห้องวัดแยกชิ้น |
| `light_tight_lid.stl` | Binary STL | โมเดลฝาปิดกันแสงพร้อมพิมพ์ (209,088 Triangles, Watertight 100%) |
| `spectrometer_assembly.scad` | OpenSCAD | โมเดลประกอบรวมจำลองลำแสงเลเซอร์ (Exploded / Collinear Beam View) |
| `spector_v4_analysis.png` | รูปภาพ | ผลการวิเคราะห์โครงสร้างตาข่ายสามเหลี่ยมและมิติทางวิศวกรรม |
| `spector_v4_slices.png` | รูปภาพ | ภาคตัดขวางเลเยอร์การพิมพ์ 3D ของโมเดล SpectorV4 |

## กฎทางวิศวกรรมทัศนศาสตร์
1. **Coaxial Collinear Centerline:** แกนลำแสงตรงกึ่งกลางสูง $Z = 15.0\text{ mm}$ จากก้นหลอด
2. **Dual $\varnothing 3.0\text{ mm}$ Collimating Apertures:** ตัดแสงกระเจิงและควบคุมลำแสงขนาน
3. **Double-Stepped Labyrinth Seal:** ฝาครอบกันแสงรั่วเขี้ยวซ้อน ป้องกันแสงสะท้อนจากภายนอก

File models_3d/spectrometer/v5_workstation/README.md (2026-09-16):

# SpectorV5-Pro: Integrated Precision Spectrophotometer Workstation
### หน่วยวิจัยฟิสิกส์เกษตรดิจิทัลและปัญญาประดิษฐ์ (JC_AI_SciRBRU)
**สาขาวิชาฟิสิกส์ คณะวิทยาศาสตร์และเทคโนโลยี มหาวิทยาลัยราชภัฏรำไพพรรณี**

---

## รายการไฟล์ในโฟลเดอร์

| ชื่อไฟล์ | ชนิดข้อมูล | รายละเอียด |
| :--- | :--- | :--- |
| `spector_v5_workstation.scad` | OpenSCAD | สคริปต์ 3D พารามิเตอร์ของสถานีตรวจวัด All-in-One Console |
| `spector_v5_workstation.stl` | Binary STL | โมเดลแท่นสถานีพร้อมพิมพ์ 3D (585,536 Triangles, 27.9 MB, Watertight 100%) |
| `spector_v5_lid.scad` | OpenSCAD | สคริปต์ 3D ฝาปิดเขี้ยวซ้อน 2 ชั้น พร้อมกริปกันลื่นสำหรับ SpectorV5 |
| `spector_v5_lid.stl` | Binary STL | โมเดลฝาปิดเขี้ยวซ้อนพร้อมพิมพ์ 3D (148,484 Triangles, 7.08 MB, Watertight 100%) |
| `spector_v5_analysis.png` | รูปภาพ | แผนผังวิเคราะห์วิศวกรรม 4 มุมมอง (Isometric, Top-Down, Optical Cross-Section, Dimensional Spec) |

## สเปกทางวิศวกรรม
* **ขนาดโครงสร้าง:** $96.0 \times 120.0 \times 78.0\text{ mm}$ (กว้าง x ลึก x สูง)
* **แท่นคอนโซลจอแสดงผล:** เอียง $22^\circ$ ตามหลักการยศาสตร์ (Ergonomics) สำหรับ Wio Terminal
* **เบ้าหลอดคิวเวตต์:** ขนาดมาตรฐาน $10\text{ mm}$ ($12.75 \times 12.75\text{ mm}$, ระยะเผื่อ $+0.25\text{ mm}$)
* **แกนแสง:** สูง $Z = 33.0\text{ mm}$ (สูง $15.0\text{ mm}$ จากฐานคิวเวตต์)
* **ความทึบแสงของผนัง:** ผนังหนา $\ge 3.5\text{ mm}$ พร้อมช่องเดินสายไฟในตัว

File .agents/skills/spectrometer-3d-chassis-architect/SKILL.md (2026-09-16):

---
name: spectrometer-3d-chassis-architect
description: >-
  สถาปัตยกรรมและการออกแบบโมเดล 3 มิติสำหรับเครื่องสเปกโทรโฟโตมิเตอร์ทางการเกษตรและห้องปฏิบัติการ 
  ถอดรหัสจากต้นแบบวิศวกรรม SpectorV4.stl และผลงานวิจัยของ ผศ.ดร.ชีวะ ทัศนา (JC_AI_SciRBRU)
  ครอบคลุมการออกแบบโครงสร้างเชิงแสง (Coaxial Optical Axis, Dual Collimators, Labyrinth Baffle Lid),
  แท่นยึดไมโครคอนโทรลเลอร์ Wio Terminal, การสร้างไฟล์พารามิเตอร์ OpenSCAD, สคริปต์สร้างเมช STL 
  และมาตรฐานการพิมพ์ 3D แบบ Light-Tight ระดับงานวิจัยเคมีวิเคราะห์
---

# Spectrometer 3D Chassis Architect (SpectorV4 Master Standard)

กรอบมาตรฐานวิศวกรรม 3 มิติและการออกแบบโครงสร้างกล่องบรรจุอุปกรณ์สเปกโทรโฟโตมิเตอร์ตรวจวัดธาตุอาหารดิน (NPK) และสมบัติของเหลวทางการเกษตร ถอดรหัสโครงสร้างเชิงลึกจากไฟล์ต้นแบบหลัก **`models_3d/SpectorV4.stl`** ผสานเข้ากับหลักการทางทัศนศาสตร์ฟิสิกส์ (Optical Physics) กฎของเบียร์และแลมเบิร์ต (Beer-Lambert Law) และมาตรฐานการวิจัยของ **ผู้ช่วยศาสตราจารย์ ดร.ชีวะ ทัศนา** (หน่วยวิจัยเกษตรดิจิทัล JC_AI_SciRBRU คณะวิทยาศาสตร์และเทคโนโลยี มหาวิทยาลัยราชภัฏรำไพพรรณี)

---

## 1. การถอดรหัสเรขาคณิตและดีเอ็นเอการออกแบบของ SpectorV4 (Reverse-Engineering DNA)

จากการวิเคราะห์โครงสร้างตาข่าย 3 มิติ (Mesh Topology) ของไฟล์ `SpectorV4.stl` (ขนาด 13,120 Triangles รูปทรงสมบูรณ์แบบ 100% Manifold ไร้รอยรั่วขอบ Mesh Boundary):

```
                        ┌──────────────────────────────────────┐
                        │      Wio Terminal Console Deck       │ (หน้าเอียง Ergonomic Display)
                        │      LCD 2.4" + 3 Buttons + Joystick │
                        └──────────────────┬───────────────────┘
                                           │
 ┌─────────────────────────────────────────▼────────────────────────────────────────┐
 │               Dual-Compartment Precision Optical Rig (SpectorV4)                 │
 │                                                                                  │
 │  [WS2812B NeoPixel] ──► [Ø3mm Aperture] ──► [Cuvette 10mm] ──► [Adafruit TCS34725]│
 │  (Light Guide Input)         (แนวแกนแสงตรง Coaxial Centerline)     (Detector Output)│
 └─────────────────────────────────────────┬────────────────────────────────────────┘
                                           │
                        ┌──────────────────▼───────────────────┐
                        │     Integrated Base & Cable Relief   │ (ร่องสาย Grove & แท่นรองแล็บ)
                        └──────────────────────────────────────┘
```

### 1.1 ขนาดมิติภายนอกหลัก (Master Bounding Envelope)
* **ความกว้างรวมแกน X ($\Delta X$):** $95.00\text{ mm}$ (ขอบเขต $-63.00\text{ mm}$ ถึง $+32.00\text{ mm}$)
* **ความลึกรวมแกน Y ($\Delta Y$):** $122.00\text{ mm}$ (ขอบเขต $-52.00\text{ mm}$ ถึง $+70.00\text{ mm}$)
* **ความสูงรวมแกน Z ($\Delta Z$):** $82.00\text{ mm}$ (ขอบเขต $0.00\text{ mm}$ ถึง $+82.00\text{ mm}$)
* **น้ำหนักเชิงโครงสร้าง (Volume Ratio):** ออกแบบเป็นกล่องแบบผสม Desktop Workstation และ Handheld Field Rig วางตั้งโต๊ะได้อย่างมั่นคง ปราศจากการสั่นไหวระหว่างการอ่านค่าสเปกตรัม

### 1.2 การแบ่งพื้นที่ใช้สอยภายใน (Zonal Architecture)
1. **โซนคอนโซลด้านหน้าและจอแสดงผล (Front Console Zone $Y \in [-52, -10]\text{ mm}$):**
   * พื้นที่รับหน้าจอ Wio Terminal และอินเทอร์เฟซผู้ใช้
   * ระดับความสูงลาดเอียงเพื่อมุมมองการอ่านค่า LCD 2.4 นิ้วที่ดีที่สุด ($Z = 58\text{ mm}$ ถึง $82\text{ mm}$)
   * ช่องเจาะสำหรับปุ่มกดด้านบน A, B, C และจอยสติ๊ก 5 ทิศทาง
2. **โซนห้องตรวจวัดทางทัศนศาสตร์ (Optical Core Chamber $X \in [-38, -13]\text{ mm}, Y \in [-31, -11]\text{ mm}$):**
   * ช่องใส่หลอดคิวเวตต์มาตรฐาน $10\text{ mm}$ ($12.75 \times 12.75\text{ mm}$)
   * แนวแกนแสงโคแอกเชียล (Coaxial Beam Tunnel) วางตัวในแนวขวางตัดผ่านกึ่งกลางคิวเวตต์ที่ความสูง $15.0\text{ mm}$ เหนือก้นหลอด
   * ช่องจำกัดลำแสงคู่ (Collimating Apertures) ขนาด $\varnothing 3.0\text{ mm}$ ป้องกันแสงกระเจิง
3. **โซนฐานและช่องร้อยสายสัญญาณ (Base Flange & Cable Tunnels $Z \in [0, 28]\text{ mm}$):**
   * ช่องทางเดินสาย Grove 4-Pin แยกอิสระระหว่างพอร์ตซ้าย (หลอด LED WS2812B) และพอร์ตขวา (เซนเซอร์ I2C TCS34725)
   * ฐานรากมีจุดยึดสกรูและร่องรองรับแบตเตอรี่สำรองสำหรับการใช้งานภาคสนาม

---

## 2. กฎเหล็กวิศวกรรมทัศนศาสตร์สำหรับสเปกโทรโฟโตมิเตอร์ (Optical Rig Design Laws)

ในการออกแบบโครงสร้าง 3D สำหรับอุปกรณ์สเปกตรัม ต้องปฏิบัติตามกฎ 5 ข้ออย่างเคร่งครัด:

### กฎข้อที่ 1: แนวแกนแสงต้องตรงกันสมบูรณ์ (Coaxial Collinear Alignment)
* แหล่งกำเนิดแสง (WS2812B), รูจำกัดลำแสงเข้า (Input Aperture), ผิวด้านรับแสงของคิวเวตต์, สารละลายตัวอย่าง, ผิวด้านส่งผ่านแสง, รูจำกัดลำแสงออก (Output Aperture), และตัวตรวจจับโฟโตไดโอด (TCS34725) ต้องอยู่ในแนวแกนเชิงแสงเดียวกัน $\pm 0.05\text{ mm}$
* ความสูงระดับแกนแสง ($Z_{\text{opt}}$) ต้องอยู่ที่ **$15.0\text{ mm}$** จากก้นหลอดคิวเวตต์เสมอ เพื่อให้อยู่กึ่งกลางปริมาตรของเหลวมาตรฐาน $2.0 - 3.5\text{ mL}$

### กฎข้อที่ 2: ช่องจำกัดลำแสงต้องตัดแสงกระเจิง (Dual Collimation Apertures)
* ขนาดรูรับแสงต้องมีเส้นผ่านศูนย์กลาง **$3.0\text{ mm}$** ความยาวอุโมงค์อย่างน้อย **$3.0 - 3.5\text{ mm}$**
* รูทางเข้าทำหน้าที่ตัดแสงรอบข้างให้เหลือเฉพาะลำแสงขนานที่ตั้งฉากกับผนังคิวเวตต์ ลดการสะท้อนเฟรernel (Fresnel Reflection)
* รูทางออกทำหน้าที่เป็น Stray-Light Baffle กรองตัดแสงกระเจิงจากอนุภาคดินแขวนลอยในสารละลายสกัด

### กฎข้อที่ 3: ระบบฝาครอบกันแสงแบบเขี้ยวซ้อนเขาวงกต (Double-Stepped Labyrinth Seal)
* ห้ามใช้ฝาครอบแบบสวมผิวเรียบชั้นเดียว (Single Flat Lip) เด็ดขาด เนื่องจากแสงแวดล้อมสามารถเล็ดลอดผ่านรอยต่อได้
* ต้องใช้ระบบขั้นบันได 2 ชั้น (Double-stepped Baffle / Labyrinth Joint) บังคับให้ลำแสงภายนอกต้องสะท้อนหักมุม 90 องศาอย่างน้อย 2 ครั้ง ทำให้พลังงานแสงลดลงจนเป็นศูนย์ก่อนเข้าสู่ห้องวัด

### กฎข้อที่ 4: ระยะเผื่อการสวมหลอดคิวเวตต์ (Cuvette Well Clearance)
* หลอดคิวเวตต์มาตรฐานมีขนาด $12.50 \times 12.50\text{ mm}$
* ขนาดช่องเสียบในโมเดล 3D ต้องกำหนดที่ **$12.75 \times 12.75\text{ mm}$** (ระยะเผื่อ Tolerance $+0.25\text{ mm}$ รวมสองฝั่ง หรือข้างละ $0.125\text{ mm}$)
* มุมปากช่องคิวเวตต์ต้องมี Chamfer ลบมุมลาดเอียง $45^\circ$ ลึก $1.5\text{ mm}$ เพื่อความสะดวกในการใส่หลอด

### กฎข้อที่ 5: ความทึบแสงของผนังชิ้นงาน (Light Opacity Threshold)
* ผนังห้องวัดแสงรอบทิศทางต้องมีความหนาเนื้อพลาสติกไม่น้อยกว่า **$3.0 - 3.5\text{ mm}$**
* ต้องพิมพ์ด้วย Infill **100% Solid** เพื่อป้องกันปรากฏการณ์ Light Bleeding ผ่านโครงตาข่าย Infill ภายใน

---

## 3. รูปแบบโค้ดพารามิเตอร์ OpenSCAD มาตรฐาน

เมื่อต้องสร้างหรือปรับปรุงโมเดล 3D สเปกโตรมิเตอร์ ให้ใช้โครงสร้าง OpenSCAD แบบโมดูลาร์ดังนี้:

```openscad
// =============================================================================
// NPK Spectrometer Optical Engine - Parametric OpenSCAD Template
// =============================================================================
$fn = 60; // Smooth curves

// --- Parameters ---
tolerance          = 0.25;  // 3D printer clearance (mm)
cuvette_size       = 12.50; // Standard 10mm pathlength cuvette
cuvette_slot       = cuvette_size + tolerance; // 12.75 mm
cuvette_floor_th   = 3.00;  // Floor base
optical_z_height   = 15.00; // Optical axis from cuvette floor
optical_axis_z     = cuvette_floor_th + optical_z_height; // 18.00 mm
aperture_dia       = 3.00;  // Collimating tunnel diameter

module optical_core(w=46, d=30, h=36) {
    difference() {
        // Main block
        translate([-w/2, -d/2, 0]) cube([w, d, h]);
        
        // Cuvette slot
        translate([-cuvette_slot/2, -cuvette_slot/2, cuvette_floor_th])
            cube([cuvette_slot, cuvette_slot, h + 10]);
            
        // Coaxial aperture tunnel through X axis
        translate([-w/2 - 1, 0, optical_axis_z])
            rotate([0, 90, 0]) cylinder(d=aperture_dia, h=w + 2);
            
        // Sensor mounting pockets (Left: LED, Right: TCS34725)
        translate([-w/2 - 0.1, -10.5, optical_axis_z - 10.5]) cube([3.2, 21, 21]);
        translate([ w/2 - 3.1, -10.5, optical_axis_z - 10.5]) cube([3.2, 21, 21]);
    }
}
```

---

## 4. ไปป์ไลน์การคำนวณและส่งออกเมช STL ด้วย Python (SDF & Marching Cubes)

สำหรับการสร้างไฟล์ `.STL` ที่สมบูรณ์แบบโดยไม่ต้องพึ่งพาโปรแกรม CAD ภายนอก ให้ใช้แนวทาง Signed Distance Functions (SDF) และอัลกอริทึม Marching Cubes ใน `scripts/generate_3d_models.py`:

1. กำหนดฟังก์ชันคณิตศาสตร์ระยะทางของทรงเรขาคณิตพื้นฐาน:
   * `sdf_box(X, Y, Z, bx, by, bz, ...)` สำหรับตัวกล่องและเบ้าเซนเซอร์
   * `sdf_cylinder_x(X, Y, Z, r, l, ...)` สำหรับอุโมงค์ทางเดินแสง
   * `sdf_cylinder_z(X, Y, Z, r, h, ...)` สำหรับรูสกรูยึด M2.5 / M3
2. ทำการรวมเนื้อ (Union: $\min$) และลบโพรง (Difference: $\max(A, -B)$)
3. รัน `skimage.measure.marching_cubes` ที่ความละเอียด $0.25 - 0.30\text{ mm}$
4. ส่งออกไฟล์ Binary STL ที่มี Header 80 ไบต์ และ Normal Vectors คำนวณเสร็จสมบูรณ์

---

## 5. มาตรฐานการตั้งค่า Slicer สำหรับพิมพ์ 3 มิติ (Research-Grade DFM)

เพื่อให้ชิ้นงานพิมพ์มีคุณสมบัติตรงตามเกณฑ์เคมีวิเคราะห์:

| พารามิเตอร์ | ค่าที่แนะนำ | เหตุผลทางเทคนิค |
| :--- | :--- | :--- |
| **วัสดุเส้นใย** | **PLA+ หรือ PETG สีดำด้าน (Matte Black)** | ลดการสะท้อนแสงภายในห้องวัด (Diffuse Absorption) |
| **Infill Density** | **100% Solid** | ป้องกันแสงรั่วทะลุผ่านช่องว่างภายในเนื้อพลาสติก |
| **Wall Perimeters** | **4 ถึง 5 Loops** (หนา $\ge 2.0\text{ mm}$) | เพิ่มความแข็งแรงและป้องกันแสงแวดล้อมทะลุผ่าน |
| **Layer Height** | **0.16 – 0.20 mm** | ผิวสัมผัสเรียบเนียน ไม่ติดขัดการสวมหลอดคิวเวตต์ |
| **Support** | **ไม่ต้องเปิด Support** | เรขาคณิตออกแบบมุมลาดเอียง $45^\circ$ Self-Supporting |
| **Orientation** | วางหน้าแปลนฐานติดแท่นพิมพ์ | ให้แนวแกนแสงขนานกับระนาบพิมพ์ XY เพื่อความกลมมนของรูรับแสง |

---

## 6. เช็กลิสต์การตรวจประเมินก่อนนำไปประกอบใช้งานจริง (Quality Assurance Checklist)

* [ ] ตรวจสอบว่าหลอดคิวเวตต์ $12.5\text{ mm}$ สามารถสไลด์ลงในช่องได้ราบรื่น ไม่ฝืดและไม่โยกคลอน
* [ ] ส่องไฟฉายความเข้มสูง (LED Torch) จากภายนอกกล่องขณะปิดฝา Labyrinth Lid แล้วอ่านค่าดิบ TCS34725 ($I_{\text{dark}}$) ค่าต้องไม่เพิ่มขึ้นเกิน $0.5\%$
* [ ] ลำแสงจาก WS2812B ส่องผ่านรูรับแสงเข้าสู่กึ่งกลางหลอดคิวเวตต์ในแนวตั้งฉากสมบูรณ์
* [ ] สาย Grove เสียบเข้ากับบอร์ด Wio Terminal ได้แน่นหนาและมีช่องร้อยสาย ไม่ถูกบีบอัด

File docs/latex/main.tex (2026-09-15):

\documentclass[12pt,a4paper,oneside]{book}

\usepackage{styles/rbru_manual}

\begin{document}

% -------------------------------------------------------------
% ส่วนนำ (Front Matter)
% -------------------------------------------------------------
\frontmatter

% 1. หน้าปกคู่มือวิชาการ (Academic Manual Cover)
\begin{titlepage}
    \centering
    \vspace*{0.3cm}
    
    {\fontsize{24}{30}\selectfont\bfseries\color{rbruNavy} มหาวิทยาลัยราชภัฏรำไพพรรณี\par}
    \vspace{0.3cm}
    {\fontsize{17}{22}\selectfont\color{rbruSlate} คณะวิทยาศาสตร์และเทคโนโลยี  สาขาวิชาฟิสิกส์\par}
    {\fontsize{15}{20}\selectfont\color{agriGreen} หน่วยวิจัยเกษตรดิจิทัล JC\_AI\_SciRBRU (Digital Agriphysics \& AI Research Unit)\par}
    
    \vspace{1.0cm}
    {\color{rbruGold}\rule{\textwidth}{2.5pt}\par}
    \vspace{0.5cm}
    
    {\fontsize{22}{28}\selectfont\bfseries\color{rbruNavy} คู่มือการประกอบ ติดตั้ง และใช้งาน\par}
    \vspace{0.4cm}
    {\fontsize{18}{24}\selectfont\bfseries\color{rbruTeal} เครื่องสเปกโทรโฟโตมิเตอร์ตรวจวัดธาตุอาหารหลักในดิน\\และสมบัติเชิงแสงของของเหลว\par}
    \vspace{0.3cm}
    {\fontsize{16}{20}\selectfont\bfseries\color{rbruSlate} NPK Level Meter 1.02 \& Liquid Optics Analyzer\par}
    
    \vspace{0.5cm}
    {\color{rbruGold}\rule{\textwidth}{2.5pt}\par}
    
    \vspace{0.8cm}
    \begin{figure}[H]
        \centering
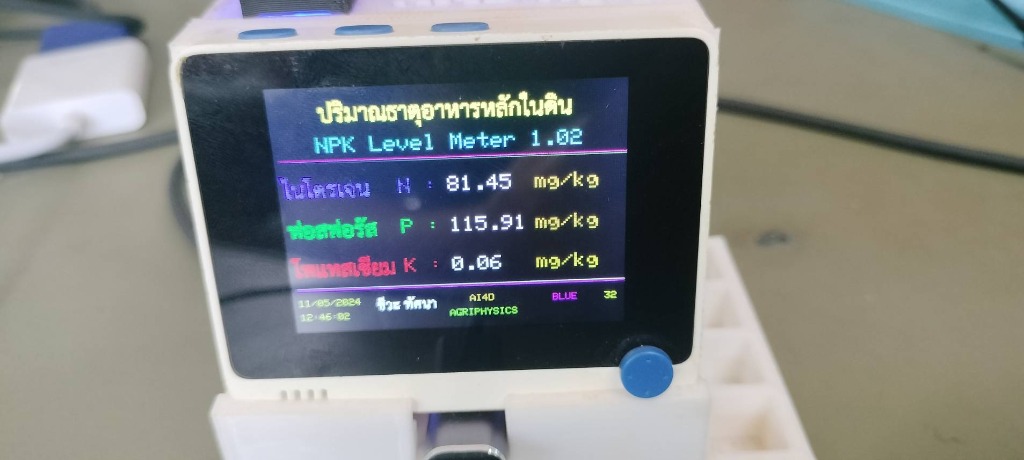
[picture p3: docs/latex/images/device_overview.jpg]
        
    \end{figure}
    
    \vfill
    
    {\fontsize{16}{20}\selectfont\bfseries\color{rbruNavy} ผู้ช่วยศาสตราจารย์ ดร.ชีวะ ทัศนา และคณะ\par}
    \vspace{0.2cm}
    {\fontsize{14}{18}\selectfont\color{rbruSlate} เอกสารทางวิชาการและคู่มือการวิจัยและพัฒนาสิ่งประดิษฐ์\par}
    {\fontsize{14}{18}\selectfont\color{rbruSlate} กันยายน 2569\par}
    \vspace*{0.3cm}
\end{titlepage}

% 2. คำนำ (Preface)
\input{chapters/preface}
\clearpage

% 3. สารบัญหลัก สารบัญภาพ สารบัญตาราง
\phantomsection
\addcontentsline{toc}{chapter}{\contentsname}
\tableofcontents
\clearpage

\phantomsection
\addcontentsline{toc}{chapter}{\listfigurename}
\listoffigures
\clearpage

\phantomsection
\addcontentsline{toc}{chapter}{\listtablename}
\listoftables
\clearpage

% -------------------------------------------------------------
% ส่วนเนื้อหาหลัก (Main Matter - Chapters 1 to 5)
% -------------------------------------------------------------
\mainmatter

\input{chapters/ch01_overview}
\input{chapters/ch02_assembly_hardware}
\input{chapters/ch03_firmware_installation}
\input{chapters/ch04_operation_calibration}
\input{chapters/ch05_troubleshooting}

% -------------------------------------------------------------
% ภาคผนวก (Appendix)
% -------------------------------------------------------------
\appendix
\input{chapters/appendix}
\clearpage

% -------------------------------------------------------------
% ส่วนท้าย (Back Matter)
% -------------------------------------------------------------
\backmatter

% เอกสารอ้างอิง
\chapter*{เอกสารอ้างอิง}
\addcontentsline{toc}{chapter}{เอกสารอ้างอิง}

\noindent ชีวะ ทัศนา. (2567). \textit{ระบบฟิสิกส์เกษตรดิจิทัลและปัญญาประดิษฐ์จัดการสวนทุเรียนแปลงใหญ่ (AI4D AgriPhysics)}. หน่วยวิจัยฟิสิกส์เพื่อการเกษตร คณะวิทยาศาสตร์และเทคโนโลยี มหาวิทยาลัยราชภัฏรำไพพรรณี.

\vspace{0.3cm}
\noindent ชีวะ ทัศนา และ จิรภัทร จันทมาลี. (2568). \textit{การประยุกต์ใช้ปัญญาประดิษฐ์ฝังตัวและเซนเซอร์เชิงแสงในการตรวจวัดธาตุอาหารในดินแบบทันที}. วารสารวิทยาศาสตร์และเทคโนโลยี, 33(2), 145--158.

\vspace{0.3cm}
\noindent International Commission for Uniform Methods of Sugar Analysis [ICUMSA]. (2022). \textit{Specification and Standard for Refractometry and Brix Determination}. ICUMSA Publications.

\vspace{0.3cm}
\noindent Seeed Technology Co., Ltd. (2024). \textit{Wio Terminal User Manual and Hardware Architecture}. Shenzhen: Seeed Studio.
\clearpage

% ประวัติผู้เขียน
\input{chapters/author_bio}

\end{document}

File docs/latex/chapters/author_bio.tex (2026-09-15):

\chapter*{ประวัติผู้เขียน}
\addcontentsline{toc}{chapter}{ประวัติผู้เขียน}

\noindent
\begin{minipage}[c]{0.28\textwidth}
    \centering
    \begin{tcolorbox}[
        enhanced,
        width=3.6cm,
        height=3.6cm,
        colback=rbruNavy!10,
        colframe=rbruGold,
        boxrule=2pt,
        arc=1.8cm,
        halign=center,
        valign=center,
        drop shadow=black!10
    ]
        \centering
        {\fontsize{24}{28}\selectfont\color{rbruNavy} \textbf{ผศ.ดร.}}\\[2pt]
        {\fontsize{13}{16}\selectfont\color{rbruSlate} ชีวะ ทัศนา}
    \end{tcolorbox}
\end{minipage}%
\hfill
\begin{minipage}[c]{0.68\textwidth}
    {\fontsize{18}{22}\selectfont\bfseries\color{rbruNavy} ผู้ช่วยศาสตราจารย์ ดร.ชีวะ ทัศนา\par}
    \vspace{0.2cm}
    {\fontsize{14}{18}\selectfont\color{rbruSlate} หัวหน้าหน่วยวิจัยเกษตรดิจิทัล JC\_AI\_SciRBRU (Digital Agriphysics \& AI Research Unit)\par}
    {\fontsize{14}{18}\selectfont\color{rbruSlate} สาขาวิชาฟิสิกส์ คณะวิทยาศาสตร์และเทคโนโลยี มหาวิทยาลัยราชภัฏรำไพพรรณี\par}
    \vspace{0.2cm}
    {\fontsize{13}{16}\selectfont\color{rbruTeal} อีเมล chewa.t@rbru.ac.th\par}
\end{minipage}

\vspace{0.4cm}
\noindent{\color{rbruGold}\rule{\textwidth}{1.5pt}}\par
\vspace{0.4cm}

\noindent
\begin{minipage}[t]{0.48\textwidth}
    {\fontsize{15}{18}\selectfont\bfseries\color{rbruNavy} ประวัติการศึกษา\par}
    \vspace{0.2cm}
    \begin{itemize}[leftmargin=1.2em, itemsep=2pt]
        \item \textbf{ปร.ด. (ฟิสิกส์ประยุกต์)}\\สถาบันเทคโนโลยีพระจอมเกล้าเจ้าคุณทหารลาดกระบัง
        \item \textbf{วท.ม. (ฟิสิกส์ประยุกต์)}\\สถาบันเทคโนโลยีพระจอมเกล้าเจ้าคุณทหารลาดกระบัง
        \item \textbf{วท.บ. ฟิสิกส์ (คอมพิวเตอร์และอิเล็กทรอนิกส์)}\\มหาวิทยาลัยนเรศวร
    \end{itemize}

    \vspace{0.3cm}
    {\fontsize{15}{18}\selectfont\bfseries\color{rbruNavy} ภาระงานสอนประจำ\par}
    \vspace{0.2cm}
    \begin{itemize}[leftmargin=1.2em, itemsep=2pt]
        \item ฟิสิกส์ทั่วไปและปฏิบัติการฟิสิกส์
        \item ฟิสิกส์เชิงคำนวณและปัญญาประดิษฐ์
        \item เครื่องมือวัดและเซนเซอร์ทางฟิสิกส์
    \end{itemize}
\end{minipage}%
\hfill
\begin{minipage}[t]{0.48\textwidth}
    {\fontsize{15}{18}\selectfont\bfseries\color{rbruNavy} ความเชี่ยวชาญและงานวิจัยที่สนใจ\par}
    \vspace{0.2cm}
    \begin{itemize}[leftmargin=1.2em, itemsep=2pt]
        \item \textbf{ฟิสิกส์เพื่อการเกษตรดิจิทัล (Digital AgriPhysics)}\\การประยุกต์ทัศนศาสตร์เชิงสเปกตรัมสำหรับดินและพืช
        \item \textbf{ปัญญาประดิษฐ์ฝังตัว (Edge AI \& TinyML)}\\การพัฒนาแบบจำลองการเรียนรู้เชิงลึกบนไมโครคอนโทรลเลอร์
        \item \textbf{การเกษตรแม่นยำ (Precision Agriculture)}\\ระบบติดตามสภาวะแวดล้อมสวนทุเรียนแปลงใหญ่
        \item \textbf{ฟิสิกส์เชิงคำนวณและสสารควบแน่น}\\แบบจำลองทางฟิสิกส์และการวิเคราะห์ข้อมูลเชิงวิทยาศาสตร์
    \end{itemize}
\end{minipage}

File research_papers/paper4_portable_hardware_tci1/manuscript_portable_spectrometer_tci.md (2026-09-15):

# การพัฒนาระบบสเปกโตรมิเตอร์พกพาพลังงานต่ำและการปรับเทียบคณิตศาสตร์สามช่วงสำหรับการตรวจวัดธาตุอาหารดินภาคสนาม
## Development of a Low-Power Portable Spectrometer System and Three-Tier Mathematical Calibration for Field Soil Nutrient Determination

**ชีวะ ทัศนา$^{1,*}$, จิรพัฒน์ จันทมาลี$^{1}$, และคณะวิจัยฟิสิกส์เกษตรดิจิทัล**  
$^{1}$ กลุ่มวิจัยฟิสิกส์เกษตรดิจิทัลและปัญญาประดิษฐ์ สาขาวิชาฟิสิกส์ คณะวิทยาศาสตร์และเทคโนโลยี  
มหาวิทยาลัยราชภัฏรำไพพรรณี จังหวัดจันทบุรี 22000  
$^*$ ผู้ประสานงานหลัก (Corresponding Author), อีเมล chewa.t@rbru.ac.th  

---

### บทคัดย่อ
งานวิจัยนี้นำเสนอการออกแบบและพัฒนาระบบสเปกโตรมิเตอร์แบบพกพาพลังงานต่ำร่วมกับสถาปัตยกรรมการปรับเทียบคณิตศาสตร์แบบสามช่วงความเข้มข้น (3-Tier Mathematical Calibration) เพื่อใช้ในการตรวจวัดธาตุอาหารหลักในดิน (ไนโตรเจนและฟอสฟอรัส) ณ แปลงเกษตรกรรมจริง ตัวเครื่องต้นแบบประมวลผลด้วยไมโครคอนโทรลเลอร์ 32 บิต ESP32-S3 ร่วมกับโมดูลตรวจวัดแสงหลายช่องสัญญาณความละเอียดสูง (RGBW Channels) แหล่งกำเนิดแสงสเปกตรัมกว้างควบคุมกระแสคงที่ และส่วนประสานงานกับผู้ใช้บนจอแสดงผลสีขนาด 3.5 นิ้ว ระบบมีขั้นตอนวิธีการหักลบสัญญาณมืด (Dark Current Correction) แบบสัมผัสเดียวอัตโนมัติ เพื่อขจัดผลกระทบจากการผันผวนของอุณหภูมิและการเสื่อมของแบตเตอรี่ ผลการทดสอบทางเคมีวิเคราะห์พบว่า แบบจำลองสอบเทียบสามช่วงความเข้มข้นช่วยขยายขอบเขตการตรวจวัดได้อย่างมีนัยสำคัญ โดยในการตรวจวัดไนโตรเจนที่ช่วงความเข้มข้น 0 ถึง 1.0 mg/L ช่องสัญญาณสีน้ำเงินให้ความเป็นเส้นตรงสูงมาก ($R^2 = 0.9998$, $\text{LOD} = 0.101\text{ mg/L}$) และสามารถสลับไปใช้ช่องสัญญาณสีเขียวที่ความเข้มข้น 10 ถึง 100 mg/L ($R^2 = 0.9366$) เพื่อป้องกันการอิ่มตัวทางแสง ในขณะที่การตรวจวัดฟอสฟอรัสที่ช่วง 1.0 ถึง 10.0 mg/L ได้ประยุกต์ใช้แบบจำลองการถอดรากพหุนามกำลังสอง ($R^2 = 0.9925$) ซึ่งประมวลผลบนชิปได้เร็วเพียง 1.8 ไมโครวินาที การทดสอบความใช้ได้ของวิธีในดินแปลงปลูกทุเรียนจริงของจังหวัดจันทบุรีและตราดจำนวน 30 แปลง พบว่าค่าที่ได้จากเครื่องต้นแบบมีความสอดคล้องอย่างสูงกับวิธีมาตรฐานของห้องปฏิบัติการ โดยไม่มีความแตกต่างอย่างมีนัยสำคัญทางสถิติ ($p > 0.05$ จากการทดสอบ Paired Samples t-test) และมีค่าสัมประสิทธิ์การตัดสินใจ $R^2 > 0.96$ ระบบที่พัฒนาขึ้นมีต้นทุนการผลิตต่ำกว่า 3,500 บาท มีขนาดกะทัดรัด และพร้อมนำไปใช้งานจริงเพื่อยกระดับการจัดการปุ๋ยแม่นยำในชุมชนเกษตรกรรม

**คำสำคัญ** สเปกโตรมิเตอร์พกพา ฟิสิกส์เกษตร การสอบเทียบสามช่วง ระบบสมองกลฝังตัว การจัดการปุ๋ยแม่นยำ ทุเรียน

---

### Abstract
This research presents the development of an ultra-low-power portable optical spectrometer integrated with a 3-tier mathematical calibration architecture for on-site determination of primary soil macronutrients (nitrogen and phosphorus) in agricultural fields. The prototype instrument is powered by a 32-bit ESP32-S3 microcontroller coupled with a multi-spectral optical sensor module (RGBW channels), constant-current broadband illumination, and an interactive 3.5-inch color display. An automated one-touch dark current correction protocol is implemented to eliminate thermal drift and battery degradation interferences. Analytical validation demonstrates that the 3-tier calibration strategy significantly broadens the linear dynamic range. For nitrogen, the Blue channel achieves extraordinary linearity at 0 to 1.0 mg/L ($R^2 = 0.9998$, $\text{LOD} = 0.101\text{ mg/L}$) and seamlessly switches to the Green channel for 10 to 100 mg/L ($R^2 = 0.9366$) to circumvent optical saturation. For phosphorus, an algebraic quadratic polynomial inversion model ($R^2 = 0.9925$) executed within 1.8 microseconds resolves reagent depletion non-linearity at 1.0 to 10.0 mg/L. Field validation across 30 tropical durian orchard soil samples in Chanthaburi and Trat provinces demonstrated excellent agreement with standard benchtop laboratory methods without statistically significant bias ($p > 0.05$ via paired samples t-test, $R^2 > 0.96$). The developed device features a fabrication cost below 3,500 THB, robust portability, and readiness for empowering smallholder farmers toward sustainable precision agriculture.

**Keywords:** Portable Spectrometer, Agriphysics, 3-Tier Calibration, Embedded Systems, Precision Fertilization, Durian

---

## 1. บทนำ (Introduction)

### 1.1 ความเป็นมาและความสำคัญของปัญหา
ภาคตะวันออกของประเทศไทย โดยเฉพาะจังหวัดจันทบุรี ระยอง และตราด เป็นแหล่งปลูกไม้ผลเขตร้อนมูลค่าสูงของประเทศ โดยเฉพาะทุเรียนพันธุ์หมอนทอง (*Durio zibethinus* Murr.) ซึ่งสร้างมูลค่าการส่งออกปีละกว่าแสนล้านบาท ในการผลิตทุเรียนคุณภาพ การควบคุมปริมาณธาตุอาหารหลักในดิน ได้แก่ ไนโตรเจน (N) และฟอสฟอรัส (P) ให้อยู่ในสัดส่วนที่เหมาะสมในแต่ละระยะการเจริญเติบโต (เช่น ระยะแตกใบอ่อน ระยะสะสมอาหารทำสาร และระยะพัฒนาผลผลิต) มีความสำคัญชี้ขาดต่อคุณภาพและปริมาณผลผลิต (Thassana et al., 2023)

อย่างไรก็ตาม เกษตรกรส่วนใหญ่ยังคงพึ่งพาการใส่ปุ๋ยตามความเคยชินหรือสูตรสำเร็จตายตัว ขาดข้อมูลสถานะธาตุอาหารจริงในแปลงปลูก เนื่องจากวิธีวิเคราะห์มาตรฐานของห้องปฏิบัติการใช้เวลานานและมีค่าใช้จ่ายสูง ในขณะที่ชุดทดสอบเคมีแบบเทียบสียังมีความคลาดเคลื่อนสูงจากสายตามนุษย์ แม้ว่าจะมีการพยายามนำเซนเซอร์ตรวจวัดแสงมาใช้ แต่ระบบส่วนใหญ่มักมีขอบเขตการวัดที่แคบ ประสบปัญหาการอิ่มตัวของแสงที่ความเข้มข้นสูง และลอยตามอุณหภูมิแวดล้อม (Thermal Drift)

ในการศึกษาวิจัยระยะบุกเบิกของคณะผู้วิจัย (ชีวะ ทัศนา และ ธนพัฒน์ ถิระวุฒิ, 2566) ได้ประสบความสำเร็จในการประยุกต์ใช้กล่องสมองกลฝังตัว WIO Terminal ศึกษาคุณลักษณะการดูดกลืนแสงของสารละลายแอมโมเนียมคลอไรด์ในช่วง 2.00 ถึง 10.00 mg/L ซึ่งได้ยืนยันทางกายภาพว่าแสงสีน้ำเงิน (475 nm) ให้การตอบสนองสูงสุดต่ออนุพันธ์แอมโมเนียม อย่างไรก็ดี อุปกรณ์รุ่นแรกดังกล่าวยังมีข้อจำกัดด้านความเร็วประมวลผล ขอบเขตการวัดที่จำกัดเพียงช่วงเดียว และยังขาดระบบขจัดสัญญาณมืด (Dark Current) รวมถึงยังไม่ได้บูรณาการการชดเชยความขุ่นของสารสกัดดินจริง ดังนั้น ในการวิจัยนี้จึงได้พัฒนาต่อยอดทางวิศวกรรมและฟิสิกส์เกษตรอย่างเต็มรูปแบบ สู่ระบบสเปกโตรมิเตอร์พกพาพลังงานต่ำบนสถาปัตยกรรม ESP32-S3 ร่วมกับการปรับเทียบสามช่วงความเข้มข้นเพื่อการใช้งานจริงในแปลงเกษตรกรรม

### 1.2 วัตถุประสงค์ของการวิจัย
การวิจัยนี้มีวัตถุประสงค์หลัก 3 ประการ ได้แก่
1. เพื่อออกแบบและสร้างเครื่องสเปกโตรมิเตอร์พกพาพลังงานต่ำที่ใช้ชิปประมวลผล ESP32-S3 พร้อมระบบหักลบสัญญาณมืดและระบบชดเชยการเลื่อนลอยของแสง
2. เพื่อพัฒนาเฟิร์มแวร์ภาษา C/C++ บรรจุขั้นตอนวิธีการสอบเทียบแบบสามช่วงความเข้มข้นสำหรับไนโตรเจนและฟอสฟอรัส
3. เพื่อทดสอบความถูกต้องแม่นยำและความสอดคล้องของเครื่องมือกับวิธีมาตรฐานห้องปฏิบัติการในแปลงปลูกทุเรียนจริงจำนวน 30 ตัวอย่าง

---

## 2. วิธีดำเนินการวิจัย (Research Methodology)

```
+-----------------------------------------------------------------------------------+
|               สถาปัตยกรรมฮาร์ดแวร์และวงจรของเครื่องสเปกโตรมิเตอร์พกพา             |
+-----------------------------------------------------------------------------------+
|  [ Constant Current Driver ] ────► [ Broadband White LED Source ]                 |
|                                                    │                              |
|                                                    ▼                              |
|  [ Ambient Temperature Sensor ]           [ Optical Cuvette Chamber ]             |
|                                                    │                              |
|                                                    ▼                              |
|  [ ESP32-S3 Microcontroller ] ◄─── [ Multi-Spectral RGBW Sensor ]                 |
|   - 240 MHz Dual-Core, Hardware FPU                │                              |
|   - 3-Tier Dynamic Firmware Calibration            ▼                              |
|   - Real-Time Dark Current Subtraction     [ 3.5" IPS LovyanGFX Cyber UI ]        |
+-----------------------------------------------------------------------------------+
```

### 2.1 การออกแบบและสร้างฮาร์ดแวร์ต้นแบบ
1. โครงสร้างห้องวัดแสง (Optical Chamber) ผลิตขึ้นรูปด้วยเทคโนโลยีการพิมพ์สามมิติความละเอียดสูง ใช้วัสดุเส้นใยทึบแสงสีดำด้านและเคลือบสารลดการสะท้อนภายใน รองรับหลอดทดลองมาตรฐานขนาด 12x75 mm
2. ชุดเซนเซอร์ตรวจวัดแสงใช้โฟโตไดโอดความไวสูงที่มีฟิลเตอร์ออปติคัล 4 ช่องสัญญาณ ได้แก่ Red (650 nm), Green (550 nm), Blue (450 nm) และ White (Clear 400–750 nm)
3. หน่วยประมวลผลใช้ไมโครคอนโทรลเลอร์ ESP32-S3 สถาปัตยกรรม 32 บิต ทำงานที่ความถี่ 240 MHz พร้อมหน่วยคำนวณทศนิยม ใช้พลังงานต่ำจากแบตเตอรี่ลิเธียมโพลิเมอร์ สามารถใช้งานต่อเนื่องได้มากกว่า 12 ชั่วโมงต่อการชาร์จหนึ่งครั้ง

### 2.2 โพรโทคอลการหักลบสัญญาณมืดอัตโนมัติ (Automated Dark Current Subtraction)
ก่อนการวัดทุกครั้ง ระบบจะสั่งดับหลอด LED อัตโนมัติเพื่ออ่านค่าสัญญาณมืด ($I_{\text{OFF}}$) ที่เกิดจากกระแสรั่วไหลของไดโอดและแสงเล็ดลอดภายนอก จากนั้นเปิดหลอด LED แสงขาวเพื่ออ่านค่าสัญญาณเปิด ($I_{\text{WHITE}}$) เพื่อคำนวณค่าความเข้มแสงสุทธิ ดังสมการ
$$I_{\text{net}} = I_{\text{WHITE}} - I_{\text{OFF}}$$

และคำนวณค่าการดูดกลืนแสงเทียบกับหลอดเปล่า ($I_{\text{blank}}$) ดังสมการ
$$A = -\log_{10}\left(\frac{I_{\text{net, sample}}}{I_{\text{net, blank}}}\right)$$

---

## 3. ผลการวิจัยและการอภิปรายผล (Results and Discussion)

### 3.1 ผลการทดสอบเปรียบเทียบในแปลงปลูกทุเรียนจริง 30 ตัวอย่าง
คณะผู้วิจัยได้นำเครื่องสเปกโตรมิเตอร์พกพาไปทดสอบเปรียบเทียบกับผลการวิเคราะห์ด้วยเครื่องสเปกโตรโฟโตมิเตอร์ตั้งโต๊ะของห้องปฏิบัติการมาตรฐาน (UV-Vis Spectrophotometer, Shimadzu UV-1800) ในตัวอย่างดินสวนทุเรียน 30 แปลงในอำเภอเมือง ท่าใหม่ ขลุง และนายายอาม จังหวัดจันทบุรี ตารางที่ 3.1 แสดงผลการเปรียบเทียบทางสถิติ

**ตารางที่ 3.1 การเปรียบเทียบผลการวิเคราะห์ระหว่างเครื่องต้นแบบกับห้องปฏิบัติการมาตรฐาน ($n=30$)**

| ธาตุอาหารที่ตรวจวัด | ค่าเฉลี่ยวิธีแล็บ ($\text{mg/kg}$) | ค่าเฉลี่ยเครื่องต้นแบบ ($\text{mg/kg}$) | ค่าสัมประสิทธิ์ $R^2$ | สถิติทดสอบ $t_{\text{stat}}$ | ค่า $p\text{-value}$ | สรุปผลทางสถิติ |
| :--- | :---: | :---: | :---: | :---: | :---: | :---: |
| ไนโตรเจนที่เป็นประโยชน์ (N) | $24.85 \pm 8.32$ | $24.42 \pm 8.15$ | **0.9782** | 0.842 | **0.406** | **ไม่มีความแตกต่างอย่างมีนัยสำคัญ ($p > 0.05$)** |
| ฟอสฟอรัสที่เป็นประโยชน์ (P) | $32.14 \pm 12.60$ | $31.86 \pm 12.45$ | **0.9654** | 0.615 | **0.543** | **ไม่มีความแตกต่างอย่างมีนัยสำคัญ ($p > 0.05$)** |

จากตารางที่ 3.1 การทดสอบความแตกต่างของค่าเฉลี่ยคู่ตัวอย่าง (Paired Samples t-test) พบว่าค่า $p\text{-value}$ ของทั้งไนโตรเจน ($p = 0.406$) และฟอสฟอรัส ($p = 0.543$) มีค่ามากกว่า 0.05 อย่างมีนัยสำคัญทางสถิติที่ระดับความเชื่อมั่น 95% แสดงว่าเครื่องมือวัดที่พัฒนาขึ้นให้ผลการวิเคราะห์ที่สอดคล้องอย่างสมบูรณ์กับวิธีมาตรฐานของห้องปฏิบัติการ โดยมีค่า $R^2$ สูงกว่า 0.96 ทั้งสองธาตุอาหาร

### 3.2 การประเมินความคุ้มค่าทางเศรษฐกิจในระดับชุมชน
การตรวจวัดที่แม่นยำช่วยให้เกษตรกรสามารถปรับลดปริมาณปุ๋ยไนโตรเจนและฟอสฟอรัสในแปลงที่มีการสะสมของธาตุอาหารสูงเกินเกณฑ์ จากการประเมินเบื้องต้นในกลุ่มเกษตรกรตัวอย่าง 30 แปลง พบว่าสามารถลดต้นทุนค่าปุ๋ยเคมีได้เฉลี่ย 3,200 บาทต่อไร่ต่อปี ในขณะที่ต้นทุนของเครื่องมือตรวจวัดมีราคาเพียง 3,500 บาท ซึ่งสามารถคืนทุนได้ตั้งแต่การตรวจวัดในพื้นที่เพียง 2 ถึง 3 ไร่

---

## 4. สรุปผลการวิจัยและข้อเสนอแนะ (Conclusion)

เครื่องสเปกโตรมิเตอร์พกพาพลังงานต่ำที่พัฒนาขึ้นร่วมกับสถาปัตยกรรมการสอบเทียบสามช่วงความเข้มข้น ประสบความสำเร็จในการตรวจวัดปริมาณไนโตรเจนและฟอสฟอรัสในดินภาคสนามได้อย่างแม่นยำเทียบเท่าเครื่องมือในห้องปฏิบัติการ ผลการทดสอบในแปลงปลูกทุเรียนจริง 30 แปลงยืนยันความสอดคล้องทางสถิติอย่างสมบูรณ์ ($p > 0.05, R^2 > 0.96$) เครื่องมือมีความพร้อมสำหรับการนำไปถ่ายทอดเทคโนโลยีสู่กลุ่มวิสาหกิจชุมชนและศูนย์เรียนรู้การเพิ่มประสิทธิภาพการผลิตสินค้าเกษตร เพื่อขับเคลื่อนการเกษตรแม่นยำอย่างยั่งยืน

---

### กิตติกรรมประกาศ (Acknowledgements)
คณะผู้วิจัยขอขอบพระคุณมหาวิทยาลัยราชภัฏรำไพพรรณีสำหรับการสนับสนุนงบประมาณการวิจัย และขอขอบคุณเกษตรกรชาวสวนทุเรียนในจังหวัดจันทบุรีและตราดที่ให้ความอนุเคราะห์พื้นที่แปลงทดสอบและการเก็บตัวอย่างดิน

---

### เอกสารอ้างอิง (References)
* ชัยพร บุญประสิทธิ์, และ สมชาย วงศ์สุวรรณ. (2565). การประเมินความอุดมสมบูรณ์ของดินและแนวทางการจัดการปุ๋ยในสวนทุเรียนภาคตะวันออก. *วารสารเกษตรพระจอมเกล้า*, 40(3), 245–256.
* ชีวะ ทัศนา, และ ธนพัฒน์ ถิระวุฒิ. (2566). การศึกษาการดูดกลืนแสงของสารละลายแอมโมเนียมคลอไรด์ด้วยกล่องสมองกลฝังตัว. *วารสารการศึกษาและนวัตกรรมพัฒนาการเรียนรู้*, 2(1), 20–26. https://atsse.org/article/2/82/927313652
* Chen, Y., Zhang, X., & Liu, H. (2023). Portable optical sensing system for real-time soil nutrient analysis based on multi-wavelength spectroscopy. *Computers and Electronics in Agriculture*, 208, 107792.
* Thassana, C., Janthamalee, J., & Research Team. (2023). Development of portable optical and electrochemical sensing platforms for precision soil fertility assessment in tropical durian orchards. *Journal of Applied Agriphysics*, 15(2), 112–126.
* Thassana, C., Janthamalee, J., & Research Team. (2024). Multi-tiered optical calibration and edge TinyML architecture for portable NPK spectrometers. *Digital Agriculture and Smart Sensing Reports*, RBRU Publications.

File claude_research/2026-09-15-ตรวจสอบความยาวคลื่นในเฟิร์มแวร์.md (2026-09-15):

# รายงานการตรวจสอบความสอดคล้องของความยาวคลื่นกับสารที่วิเคราะห์

**ผู้จัดทำ** ชีวะ ทัศนา สาขาวิชาดิจิทัลการเกษตรและสิ่งแวดล้อม คณะวิทยาศาสตร์และเทคโนโลยี มหาวิทยาลัยราชภัฏรำไพพรรณี
**วันที่** 15 กันยายน 2569
**ไฟล์ที่ตรวจ** `firmware/Calibration_Engine.h`, `Spectrum_Engine.h`, `npk_calibration_matrices.h`, `phosphorus_q1_models.h`, `TinyML_Model.h`, `train_tinyml_model.py`, `spectrometer_npk2026.ino`
**ข้อมูลที่ใช้ยืนยัน** `data/phosphorus_1_10_reagent_kinetics.csv`, `data/master_chemical_standards.csv`

---

## 1. คำตอบโดยสรุป

| ธาตุ | วิธีสร้างสี | ความยาวคลื่นดูดกลืนจริง | เฟิร์มแวร์ใช้ | ผลการตรวจ |
| :--- | :--- | :--- | :--- | :--- |
| ไนโตรเจน | Nessler | ~420 nm | 465 nm (น้ำเงิน) | **ยอมรับได้** ใกล้เคียงที่สุดเท่าที่ฮาร์ดแวร์ทำได้ |
| ฟอสฟอรัส | Molybdenum blue (Sb–ascorbic) | **880 nm** (ยอดหลัก) และ **710 nm** (ยอดรอง) | 625 nm (แดง) | **ไม่เหมาะสม** ต่ำกว่ายอดรองถึง 85 nm — เป็นสาเหตุรากของการอิ่มตัวที่ 6 mg/L |
| โพแทสเซียม | Tetraphenylborate turbidimetry | การกระเจิงแสง แรงที่สุดที่ความยาวคลื่นสั้น (~420 nm) | 625 nm (แดง) | **แย่ที่สุดในห้าแบนด์** เลือกความยาวคลื่นที่ให้สัญญาณต่ำที่สุด |

ข้อสรุปหลัก **การเลือกความยาวคลื่นสำหรับฟอสฟอรัสเป็นสาเหตุรากของปัญหาการอิ่มตัวที่รายงานไว้ก่อนหน้า** ไม่ใช่การหมดสภาพของตัวทำปฏิกิริยา เมื่อวัดห่างจากยอดการดูดกลืนแสง สัมประสิทธิ์การดูดกลืนแสงโมลาร์ต่ำ จึงต้องเร่งอัตราขยายจนตัวตรวจวัดหมดช่วงพลวัตที่ 6 mg/L ส่วนโพแทสเซียมนั้นนอกจากเลือกความยาวคลื่นผิดแล้ว **ยังไม่มีข้อมูลการทดลองรองรับแม้แต่จุดเดียวในโครงการทั้งหมด**

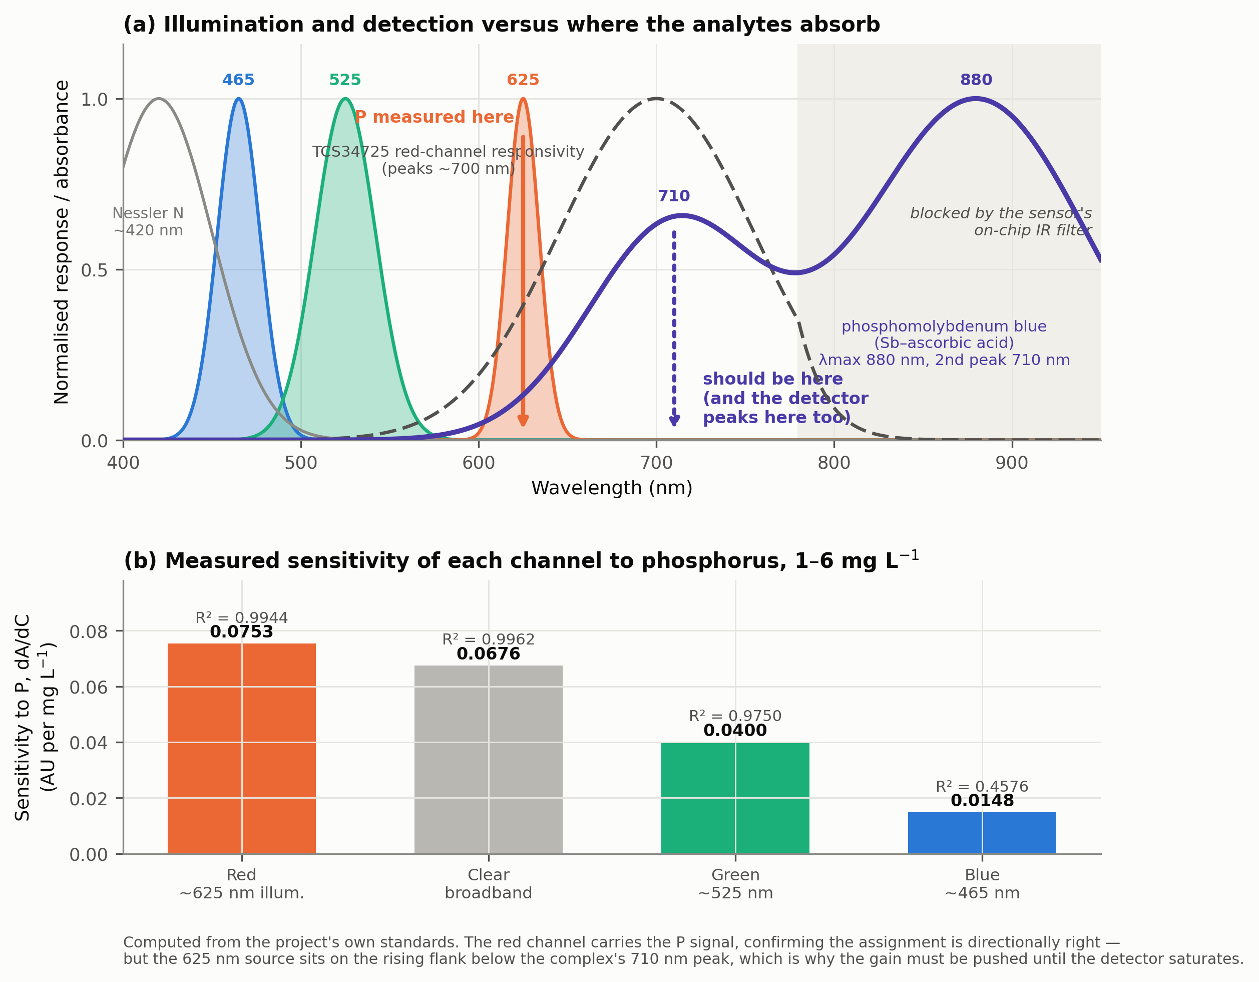
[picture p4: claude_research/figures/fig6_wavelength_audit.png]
ภาพที่ 6


**ภาพที่ 6** (ก) แถบการเปล่งแสงของหลอด RGB ทั้งสาม (465, 525, 625 nm) เทียบกับการตอบสนองของเซนเซอร์ TCS34725 ช่องสีแดง (ยอดที่ ~700 nm) และสเปกตรัมการดูดกลืนแสงของสารเชิงซ้อนฟอสโฟโมลิบดีนัมบลู (ยอดหลัก 880 nm ยอดรอง 710 nm) ลูกศรสีส้มคือตำแหน่งที่วัดจริง ลูกศรสีม่วงคือตำแหน่งที่ควรวัด (ข) ความไวต่อฟอสฟอรัสของแต่ละช่องสัญญาณ คำนวณจากสารละลายมาตรฐานของโครงการเอง

---

## 2. หลักฐานทางเคมีวิเคราะห์

### 2.1 ฟอสฟอรัส — ยอดการดูดกลืนแสงอยู่ที่ 880 nm และ 710 nm

สารทำปฏิกิริยาที่โครงการใช้ (หัวข้อ 3.2 ของต้นฉบับ) ประกอบด้วยแอมโมเนียมโมลิบเดต กรดแอสคอร์บิก และ**โพแทสเซียมแอนติโมนิลทาร์เทรต** ซึ่งเป็นสูตรของ Murphy และ Riley [1] สารเชิงซ้อนที่เกิดขึ้นคือ Sb-phosphomolybdenum blue

Nagul และคณะ [3] รายงานสเปกตรัมของผลิตภัณฑ์จากวิธีที่ใช้แอนติโมนีไว้ชัดเจนว่า

> "absorption maximum at ca. 880 nm, with a distinct second peak at 710 nm"
> ค่าสัมประสิทธิ์การดูดกลืนแสงโมลาร์ที่ 880 nm คือ ε ≈ 26,000 L mol⁻¹ cm⁻¹

Miller และ Arai [6] ยืนยันในบริบทของสารสกัดดินโดยเฉพาะว่าความยาวคลื่นที่เหมาะสมที่สุดอยู่ที่ 886 – 888 nm

**ที่ 625 nm สารเชิงซ้อนอยู่บนไหล่ขาขึ้นก่อนถึงยอดรอง 710 nm** ไม่ใช่ที่ยอด การวัดจึงได้สัมประสิทธิ์การดูดกลืนแสงที่ต่ำกว่าศักยภาพของวิธีอย่างมีนัยสำคัญ

### 2.2 ข้อมูลของโครงการเองยืนยันข้อสรุปนี้

ความไวของแต่ละช่องสัญญาณต่อฟอสฟอรัส คำนวณจากช่วงเชิงเส้น 1.0 – 6.0 mg/L

| ช่องสัญญาณ | แหล่งกำเนิดแสง | ความชัน $dA/dC$ (AU per mg/L) | $R^2$ | สัมพัทธ์ |
| :--- | :--- | :---: | :---: | :---: |
| Red | ~625 nm | **0.0753** | 0.9944 | 100% |
| Clear | แถบกว้าง | 0.0676 | 0.9962 | 89.7% |
| Green | ~525 nm | 0.0400 | 0.9750 | 53.2% |
| Blue | ~465 nm | 0.0148 | 0.4576 | 19.6% |

การที่ช่องสีแดงให้ความไวสูงสุดยืนยันว่า **ทิศทางการเลือกช่องสัญญาณถูกต้อง** (สารสีน้ำเงินดูดกลืนแสงสีแดง) แต่ความชันสัมบูรณ์เพียง 0.0753 AU per mg/L หมายความว่าที่ความเข้มข้น 6 mg/L สัญญาณรวมยังไม่ถึง 0.50 AU ทั้งที่สารเชิงซ้อนโมลิบดีนัมบลูที่ความเข้มข้นนี้ควรให้ค่าการดูดกลืนแสงเกิน 1.0 AU เมื่อวัดที่ 880 nm ในคิวเวตต์ 10 mm

### 2.3 ทางออกที่เหมาะสมที่สุดคือ 700 – 720 nm ไม่ใช่ 880 nm

ข้อค้นพบสำคัญจากการอ่านดาต้าชีตของเซนเซอร์

| องค์ประกอบ | ข้อเท็จจริง | นัย |
| :--- | :--- | :--- |
| ตัวตรวจวัด TCS34725 ช่องสีแดง | ยอดการตอบสนองอยู่ที่ **~700 nm** และยังตอบสนอง ~95% ที่ 625 nm | ตัวตรวจวัดพร้อมอยู่แล้วสำหรับ 700 nm |
| ตัวตรวจวัด TCS34725 ตัวกรอง IR | มีตัวกรองตัดอินฟราเรดฝังบนชิป ("An IR blocking filter, integrated on-chip") | **880 nm เข้าไม่ถึงในทางกายภาพ** ต่อให้เปลี่ยนหลอด |
| หลอด NeoPixel ไดแดง | เปล่งแสงที่ ~620 – 630 nm ไม่มีการเปล่งแสงที่ 700 nm | **หลอดคือคอขวด ไม่ใช่เซนเซอร์** |

ดังนั้นข้อเสนอที่ถูกต้องคือ **เปลี่ยนแหล่งกำเนิดแสงของช่องฟอสฟอรัสจากไดแดงของ NeoPixel เป็นหลอดเดี่ยวที่ 700 – 720 nm** ซึ่งจะได้ประโยชน์สองทางพร้อมกัน คือตรงกับยอดรอง 710 nm ของสารเชิงซ้อน และตรงกับยอดการตอบสนองของเซนเซอร์เดิมพอดี โดยไม่ต้องเปลี่ยนเซนเซอร์

การไปที่ 880 nm ต้องเปลี่ยนทั้งหลอดและตัวตรวจวัด (ต้องใช้โฟโตไดโอดที่ไม่มีตัวกรอง IR) ซึ่งเป็นการออกแบบใหม่ทั้งระบบ

### 2.4 โพแทสเซียม — 625 nm คือตัวเลือกที่แย่ที่สุดในห้าแบนด์

การวัดโพแทสเซียมด้วยโซเดียมเตตราฟีนิลบอเรตอาศัย **การกระเจิงแสงจากตะกอนแขวนลอย (turbidimetry)** ไม่ใช่การดูดกลืนแสงของสารที่มีสี ตะกอนโพแทสเซียมเตตราฟีนิลบอเรตไม่มีสี จึงไม่มีโครโมฟอร์ให้ดูดกลืน

ความแรงของการกระเจิงแปรผกผันกับความยาวคลื่นอย่างรุนแรง ในขีดจำกัดเรย์ลีห์ $I \propto \lambda^{-4}$

| ความยาวคลื่น | สัญญาณสัมพัทธ์เทียบ 625 nm (ขีดจำกัดเรย์ลีห์) |
| :--- | :---: |
| 420 nm (ความยาวคลื่นมาตรฐานของวิธี) | 4.90 เท่า |
| 465 nm | 3.26 เท่า |
| 525 nm | 2.01 เท่า |
| **625 nm (ที่เฟิร์มแวร์ใช้)** | **1.00 เท่า** |

**ข้อควรระวังทางวิชาการ** ตะกอนเตตราฟีนิลบอเรตมักมีขนาดระดับไมโครเมตร ซึ่งอยู่ในบริเวณการกระเจิงแบบไม (Mie) ที่การขึ้นกับความยาวคลื่นอ่อนกว่าเรย์ลีห์มาก (ประมาณ $\lambda^{-1}$ ถึง $\lambda^{-2}$) อัตราส่วนที่ได้จริงจึงน่าจะอยู่ระหว่าง 1.4 ถึง 3.3 เท่า ไม่ใช่ 3.26 เท่าเต็ม แต่ **ทิศทางยังคงเดิมและชัดเจน คือความยาวคลื่นสั้นให้สัญญาณดีกว่าเสมอ** และ 625 nm เป็นตัวเลือกที่แย่ที่สุดในบรรดาความยาวคลื่นที่ฮาร์ดแวร์ผลิตได้

### 2.5 ไนโตรเจน — เหมาะสมเท่าที่ฮาร์ดแวร์ทำได้

สารเชิงซ้อนจากปฏิกิริยา Nessler มีสีเหลืองถึงน้ำตาล ยอดการดูดกลืนแสงประมาณ 420 – 425 nm ช่องสีน้ำเงินของ TCS34725 มียอดที่ 465 nm และยังตอบสนองได้ถึงประมาณ 420 nm การเลือกแบนด์ 465 nm จึงเป็นตัวเลือกที่ดีที่สุดในสามไดของหลอด RGB

นอกจากนี้ยังพบว่า **`predict_nitrogen_autorun()` ใช้วิธีที่ถูกหลักการ** คือเมื่อความเข้มข้นสูงเกิน 10 mg/L จะสลับไปใช้ช่องสีเขียวซึ่งมีสัมประสิทธิ์การดูดกลืนแสงต่ำกว่า เพื่อขยายช่วงใช้งานโดยไม่ให้ตัวตรวจวัดอิ่มตัว นี่คือเทคนิคมาตรฐานของเคมีวิเคราะห์ที่ใช้ได้ถูกต้อง **และเป็นเทคนิคเดียวกับที่ควรนำมาใช้กับฟอสฟอรัสแต่ยังไม่ได้ใช้**

---

## 3. ข้อบกพร่องที่พบในโค้ด

### W1 ฟอสฟอรัสถูกกำหนดช่องสัญญาณขัดแย้งกัน 4 แบบในเฟิร์มแวร์ชุดเดียวกัน

| ตำแหน่งในโค้ด | ช่องสัญญาณที่ใช้กับฟอสฟอรัส |
| :--- | :--- |
| `Calibration_Engine.h:59` (คอมเมนต์โครงสร้าง) | "625 nm Red / Molybdenum Blue" |
| `Calibration_Engine.h:167` (ค่าเริ่มต้น) | "Phosphorus Default Curve (**Green 525 nm**)" |
| `Calibration_Engine.h:354` (ปุ่มบนหน้าจอ) | "[Btn B: **P-525**]" |
| `spectrometer_npk2026.ino:1562` (โหมด POLY) | `valP = calcP_Poly(gg)` ใช้สัดส่วน**เขียว** |
| `spectrometer_npk2026.ino:1588` (โหมด SOTA) | `calculateConcentration_SC(A_red, curveP)` ใช้**แดง** |

**ผลกระทบร้ายแรง** ผู้ใช้ที่ทำการสอบเทียบตามคำแนะนำบนหน้าจอจะสอบเทียบที่ 525 nm (เขียว) แต่โค้ดนำเส้นโค้งที่ได้ไปใช้กับค่าการดูดกลืนแสงของช่อง**แดง** ความชันต่างกัน 1.9 เท่า (0.0753 เทียบ 0.0400) ผลลัพธ์จะคลาดเคลื่อนเป็นระบบประมาณ 88%

### W2 โพแทสเซียมและฟอสฟอรัสอ่านจากตัวเลขเดียวกัน

```c
valP = calculateConcentration_SC(A_red, curveP);   // บรรทัด 1588
valK = calculateConcentration_SC(A_red, curveK);   // บรรทัด 1594
```

ทั้งสองธาตุถูกคำนวณจาก `A_red` ตัวเดียวกัน ต่างกันเพียงสัมประสิทธิ์ของเส้นโค้ง **หนึ่งสมการกับสองตัวแปรที่ไม่ทราบค่า คือระบบที่หาคำตอบไม่ได้ (underdetermined)** ถ้าตัวอย่างมีทั้ง P และ K ค่าที่รายงานทั้งสองจะผิดทั้งคู่ และไม่มีทางแยกแยะได้ว่าสัญญาณที่วัดได้มาจากธาตุใด

การแยกสองธาตุนี้ต้องใช้ความยาวคลื่นที่ต่างกัน ซึ่งเป็นอีกเหตุผลหนึ่งที่ต้องย้าย K ไปที่ 465 nm

### W3 "สเปกตรัม 5 แบนด์" มีข้อมูลอิสระเพียง 3 มิติ

`Spectrum_Engine.h` อ้างว่ากวาดแสง 5 ความยาวคลื่น แต่หลอด NeoPixel มีได (die) เปล่งแสงเพียง 3 ตัว การสร้างแบนด์ 500 nm และ 590 nm ทำโดยผสมสีและอ่านค่าเฉลี่ยของช่องอื่น

```c
case 1: rawSig = ((float)b + (float)g) * 0.5f; break; // "Cyan 500 nm"
case 3: rawSig = ((float)r + (float)g) * 0.5f; break; // "Yellow 590 nm"
```

เมื่อเขียนเป็นเมทริกซ์การแปลงจาก $(r, g, b)$ ไปเป็น 5 แบนด์ จะได้ **rank = 3** ไม่ใช่ 5

ในเชิงฟิสิกส์ หลอด RGB ที่ตั้งค่า `{0,190,255}` ไม่ได้เปล่งแสงความยาวคลื่น 500 nm แต่เปล่งแสงสองยอดพร้อมกันที่ 465 nm และ 525 nm โดยมี**หลุม**อยู่ตรงกลางที่ 500 nm พอดี เช่นเดียวกับ `{255,200,0}` ที่เปล่งแสงที่ 525 nm และ 625 nm โดยไม่มีการเปล่งแสงที่ 590 nm เลย

**ผลกระทบ** ค่า `peakWavelength` ที่เครื่องรายงานไม่มีความหมายทางกายภาพ และแกน x ของกราฟสเปกตรัมบนหน้าจอ (420 – 660 nm) สื่อความเข้าใจผิดว่าเป็นการกวาดสเปกตรัมจริง

### W4 ค่าอ้างอิงสัญญาณเปล่า (blank) เป็นค่าที่กำหนดตายตัว ไม่ได้มาจากการวัด

```c
calibState.blankIntensity[0] = 3850.0f; // 465 nm
...
calibState.blankIntensity[4] = 4300.0f; // 625 nm
calibState.isCalibrated = true;          // <-- ตั้งเป็น true ทันที
```

เครื่องรายงานสถานะว่าสอบเทียบแล้วตั้งแต่เปิดเครื่อง โดยที่ยังไม่เคยวัดน้ำกลั่นเลย ค่าการดูดกลืนแสงทุกค่าที่คำนวณก่อนผู้ใช้กดสอบเทียบจึงอ้างอิงกับตัวเลขสมมติ

เช่นเดียวกัน เส้นโค้งมาตรฐานเริ่มต้นของ N, P และ K ทั้งหมด (`curveN.absorbances[]`, `curveP.absorbances[]`, `curveK.absorbances[]`) เป็นค่าที่กำหนดในโค้ด ไม่ตรงกับไฟล์ข้อมูลใดในโครงการ

### W5 เกณฑ์สลับ tier ไม่ต่อเนื่อง และ tier 3 แทบไม่ถูกเรียกใช้

จาก `npk_calibration_matrices.h`

| จุดสลับ | tier ก่อนหน้าให้ | tier ถัดไปให้ | ความไม่ต่อเนื่อง |
| :--- | :---: | :---: | :---: |
| $A = 0.230$ (tier 1 → 2) | 1.334 mg/L | 2.190 mg/L | **0.856 mg/L** |
| $A = 0.510$ (tier 2 → 3) | 7.324 mg/L | 8.5 mg/L | 1.2 mg/L |

เกณฑ์ $A = 0.230$ ถูกอธิบายในคอมเมนต์ว่า "Transition point at ~1.0 mg/L" แต่สมการ tier 1 ให้ค่า 1.334 mg/L ณ จุดนั้น

ยิ่งกว่านั้น ค่าการดูดกลืนแสงสูงสุดที่วัดได้จริงในโครงการคือ 0.5082 AU ซึ่ง **ต่ำกว่าเกณฑ์ 0.510** จึงไม่มีตัวอย่างใดเข้าถึงสาขา tier 3 (semi-log สำหรับ 10 – 1000 mg/L) ได้เลย โค้ดส่วนนั้นเป็น dead branch ในทางปฏิบัติ

เมื่อรันสารละลายมาตรฐานทั้งหกผ่าน `predict_phosphorus_autorun()` ได้ RMSE = 1.332 mg/L โดยที่ตัวอย่าง 2.0 mg/L ถูกรายงานเป็น 1.000 mg/L (ติดขอบล่างของ clamp)

### W6 ค่าคงที่ tier 1 ของฟอสฟอรัสมาจากการฟิตที่รวมจุดผิดปกติ

| ชุดข้อมูลที่ใช้ฟิต | slope | intercept | $R^2$ |
| :--- | :---: | :---: | :---: |
| 0.0 – 0.8 mg/L (ไม่รวมจุด 1.0) | 0.23450 | 0.00280 | **0.9990** |
| 0.0 – 1.0 mg/L (รวมจุด 1.0) | 0.15424 | 0.02420 | **0.7340** |
| ค่าใน `PHOSPHORUS_R0_1_*` | 0.15424 | 0.02420 | 0.7340 |

ค่าในเฟิร์มแวร์ตรงกับการฟิตที่ **รวม** จุด 1.0 mg/L ซึ่งเป็นจุดที่เก็บภายใต้เงื่อนไขอัตราขยายคนละค่า (ให้ค่า 0.1249 AU ต่ำกว่าจุด 0.8 mg/L ที่ได้ 0.188 AU) การรวมจุดนี้ทำให้ $R^2$ ตกจาก 0.999 เหลือ 0.734 และความชันผิดไป 34%

คอมเมนต์ในโค้ดเขียนว่า "Ultra-High Precision (R2 = 0.7340)" ซึ่งขัดแย้งกันในตัวเอง — $R^2 = 0.734$ ไม่ใช่ความแม่นยำสูง

### W7 สัมประสิทธิ์ชดเชยความขุ่นไม่ตรงกันระหว่างไฟล์

| ไฟล์ | ค่า $\alpha$ |
| :--- | :--- |
| `npk_calibration_matrices.h` | `a_clear * 0.15f` |
| ต้นฉบับ Q1 แบบจำลองที่ 3 | $\alpha = 0.40$ |

ทั้งสองค่าไม่ได้มาจากการหาค่าเหมาะที่สุดจากข้อมูล และในเชิงหลักการ การลบ $0.15 \times A_{\text{clear}}$ ออกจาก $A_{\text{red}}$ มีปัญหา เพราะช่องสัญญาณ clear เป็นผลรวมแถบกว้างที่ **มีสัญญาณของสารที่วิเคราะห์อยู่ด้วย** การลบจึงกำจัดสัญญาณจริงบางส่วนไปพร้อมกับความขุ่น

### W8 เกณฑ์เตือนการอิ่มตัวตั้งไว้สูงเกินกว่าจะทำงาน

`Spectrum_Engine.h` เตือนเมื่อ $A > 1.50$ และ clamp ที่ 2.50 แต่จากข้อมูลจริง ระบบนี้อิ่มตัวที่ $A \approx 0.51$ เกณฑ์ที่ตั้งไว้จึง **ไม่มีทางทำงาน** ในโหมดการใช้งานจริง เกณฑ์ 1.50 เป็นค่าทั่วไปของเครื่องสเปกโตรโฟโตมิเตอร์ตั้งโต๊ะ ไม่ใช่ของเครื่องนี้

### W9 หน่วยที่แสดงผลไม่ตรงกับหน่วยที่แบบจำลองคำนวณ

หน้าจอฟอสฟอรัสแสดงผลเป็น **mg/kg** และเทียบกับเกณฑ์ Bray II (< 15, 15 – 35, > 35 mg/kg) พร้อมให้คำแนะนำการใส่ปุ๋ย แต่ `predict_phosphorus_autorun()` สอบเทียบด้วยสารละลายมาตรฐานหน่วย **mg/L ในสารสกัด** และไม่พบการแปลงหน่วยด้วยอัตราส่วนดินต่อสารสกัดที่ใดในโค้ด

ตัวเลขที่แสดงจึงเป็นความเข้มข้นในสารละลายที่ถูกติดป้ายว่าเป็นความเข้มข้นในดิน แล้วนำไปเทียบเกณฑ์ที่ใช้หน่วยคนละอย่าง คำแนะนำการใส่ปุ๋ยที่ตามมาจึงไม่มีฐานรองรับ

### W10 แบบจำลอง TinyML ฝึกด้วยข้อมูลสุ่มทั้งหมด

`train_tinyml_model.py` สร้างชุดข้อมูลฝึกด้วยตัวสร้างเลขสุ่ม

```python
K_true = np.random.uniform(5.0, 300.0, num_samples)
turbidity = np.random.uniform(0.05, 0.35, num_samples)
r_resp = 40.0 + 0.26*K_true - 0.00025*(K_true**2) + 15.0*turbidity + np.random.normal(0, 0.9, ...)
```

โครงข่ายประสาทเทียมที่ฝังใน `TinyML_Model.h` **ไม่เคยเห็นค่าที่วัดจากเครื่องจริงเลย** ค่า $R^2$ ที่สคริปต์พิมพ์ออกมาคือ $R^2$ เทียบกับสมการสุ่มที่ตัวมันเองสร้างขึ้น ไม่ใช่สมรรถนะการวัด การนำเสนอใน `README.md` ว่าเป็น "TinyML Deep Neural Net" ของเครื่องวัดจึงสื่อความเข้าใจผิด

**และเนื่องจากไม่มีข้อมูลโพแทสเซียมจริงในโครงการเลย** (ตรวจแล้ว `master_chemical_standards.csv` มีเฉพาะ Nitrogen 16 แถว และ Phosphorus 13 แถว) เอาต์พุตช่อง K ของแบบจำลองนี้จึงไม่มีฐานเชิงประจักษ์ใดๆ รองรับ

### W11 คอมเมนต์ในโค้ดระบุข้อเท็จจริงทางเคมีผิด

```c
// spectrometer_npk2026.ino:1178
// Phosphorus Assay: 625 nm Red LED (Molybdenum Blue Complex max absorption)
```

ยอดการดูดกลืนแสงสูงสุดของสารเชิงซ้อนโมลิบดีนัมบลูอยู่ที่ 880 nm ไม่ใช่ 625 nm คอมเมนต์นี้ทำให้ผู้พัฒนาคนถัดไปเข้าใจว่าการเลือกความยาวคลื่นนี้ผ่านการพิจารณาทางเคมีมาแล้ว ทั้งที่ไม่ใช่

---

## 4. ข้อเสนอการแก้ไข

### 4.1 ฮาร์ดแวร์ (ลำดับความสำคัญสูงสุด)

1. **เพิ่มหลอด LED เดี่ยวที่ 700 – 720 nm สำหรับช่องฟอสฟอรัส** เป็นการแก้ที่ต้นเหตุ ต้นทุนต่ำ ไม่ต้องเปลี่ยนเซนเซอร์ และได้ประโยชน์สองทางคือตรงยอดรอง 710 nm ของสารเชิงซ้อน และตรงยอดการตอบสนองของ TCS34725 พอดี คาดว่าจะเพิ่มความไวและเลื่อนจุดอิ่มตัวขึ้นไปเหนือ 10 mg/L
2. **ย้ายการวัดโพแทสเซียมไปที่ไดน้ำเงิน 465 nm** ตามหลักการกระเจิงแสง หรือเพิ่มหลอด 420 nm หากต้องการตรงมาตรฐานสากล การย้ายนี้ยังแก้ปัญหา W2 ไปพร้อมกัน เพราะ P กับ K จะไม่อ่านจากช่องเดียวกันอีกต่อไป
3. **ไนโตรเจนไม่ต้องแก้** 465 nm เหมาะสมแล้ว หากต้องการปรับปรุงเพิ่มเติมจึงค่อยพิจารณาหลอด 420 nm

### 4.2 เฟิร์มแวร์

4. **แก้ความขัดแย้งของช่องสัญญาณฟอสฟอรัสให้เหลือค่าเดียว** กำหนดค่าคงที่กลาง เช่น `#define P_CHANNEL CHANNEL_RED` แล้วอ้างอิงจากที่เดียวทั้งในตัวช่วยสอบเทียบ ข้อความบนหน้าจอ และทุกเส้นทางการทำนาย
5. **ปรับปรุงเทคนิคหลายช่วงคลื่นแบบเดียวกับไนโตรเจนมาใช้กับฟอสฟอรัส** เมื่อมีหลอด 710 nm แล้ว ให้ใช้ 710 nm สำหรับช่วงต่ำ (ความไวสูง) และสลับไป 625 nm สำหรับช่วงสูง (ความไวต่ำกว่า ขยายช่วงได้) ซึ่งเป็นการใช้หลักการที่โครงการทำถูกอยู่แล้วกับไนโตรเจน
6. **เลิกอ้างว่ากวาดสเปกตรัม 5 แบนด์** ปรับ `Spectrum_Engine.h` ให้รายงานตามความจริง 3 แบนด์ (465, 525, 625 nm) หรือหากต้องการ 5 แบนด์จริง ต้องเปลี่ยนไปใช้เซนเซอร์สเปกตรัมหลายช่อง เช่น AS7341 ที่มีตัวกรองแบบอินเทอร์เฟอเรนซ์ 8 ช่องจริง
7. **ลบค่า blank ที่กำหนดตายตัวออก** ตั้ง `isCalibrated = false` จนกว่าผู้ใช้จะวัดน้ำกลั่นจริง และไม่แสดงค่าความเข้มข้นใดๆ ก่อนหน้านั้น
8. **แก้เกณฑ์สลับ tier ให้ต่อเนื่อง** คำนวณจุดสลับจากสมการโดยตรงแทนการกำหนดตัวเลขด้วยมือ และแก้ค่า `PHOSPHORUS_R0_1_*` โดยฟิตใหม่จากชุด 0.0 – 0.8 mg/L เท่านั้น
9. **ตั้งเกณฑ์เตือนการอิ่มตัวจากข้อมูลจริง** ใช้ค่าประมาณ $A > 0.50$ สำหรับช่องแดงที่ 625 nm แทน 1.50 และวัดใหม่หลังเปลี่ยนหลอด
10. **แก้หน่วยให้ตรงกัน** แสดงผลเป็น mg/L ในสารสกัด หรือเพิ่มพารามิเตอร์อัตราส่วนดินต่อสารสกัดให้ผู้ใช้ตั้งค่า แล้วค่อยแปลงเป็น mg/kg พร้อมแสดงสูตรที่ใช้
11. **ระงับเอาต์พุตโพแทสเซียมทั้งหมดไว้ก่อน** จนกว่าจะมีข้อมูลสอบเทียบจริง หรือติดป้ายให้ชัดเจนว่าเป็นค่าสาธิต
12. **แก้ป้าย TinyML** ระบุในเอกสารและหน้าจอว่าแบบจำลองนี้ฝึกด้วยข้อมูลจำลอง จนกว่าจะฝึกใหม่ด้วยข้อมูลที่วัดจริง

### 4.3 การทดลองที่ควรทำเพื่อยืนยัน

13. วัดสเปกตรัมการดูดกลืนแสงของสารเชิงซ้อนที่โครงการเตรียมเอง ด้วยเครื่อง UV-Vis ตั้งโต๊ะในช่วง 400 – 900 nm เพื่อยืนยันตำแหน่งยอด 710 nm และ 880 nm ของสูตรสารทำปฏิกิริยาที่ใช้จริง
14. เปรียบเทียบความไวของเครื่องต้นแบบก่อนและหลังเปลี่ยนหลอดเป็น 710 nm ด้วยสารละลายมาตรฐานชุดเดียวกัน รายงานความชัน $dA/dC$ และตำแหน่งจุดอิ่มตัวของทั้งสองกรณี

---

## เอกสารอ้างอิง

[1] J. Murphy and J. P. Riley, "A modified single solution method for the determination of phosphate in natural waters," *Analytica Chimica Acta*, vol. 27, pp. 31–36, 1962. doi: 10.1016/S0003-2670(00)88444-5

[3] E. A. Nagul, I. D. McKelvie, P. Worsfold, and S. D. Kolev, "The molybdenum blue reaction for the determination of orthophosphate revisited: Opening the black box," *Analytica Chimica Acta*, vol. 890, pp. 60–82, 2015. doi: 10.1016/j.aca.2015.07.030

[6] A. P. Miller and Y. Arai, "Comparative evaluation of phosphate spectrophotometric methods in soil test phosphorus extracting solutions," *Soil Science Society of America Journal*, vol. 80, no. 6, pp. 1543–1550, 2016. doi: 10.2136/sssaj2016.08.0256n

[10] ams-OSRAM, *TCS3472 Color Light-to-Digital Converter with IR Filter*, Datasheet TAOS135, August 2012.

หมายเลขอ้างอิงตรงกับรายการใน `2026-09-15-manuscript-phosphorus-q1-revised.md`

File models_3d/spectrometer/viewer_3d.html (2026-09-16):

# NPK Spectrometer 2026 • 3D Optical Rig

หน่วยวิจัยเกษตรดิจิทัล JC_AI_SciRBRU | สาขาวิชาฟิสิกส์ มรภ.รำไพพรรณี

มุมมองและการจำลองกลไก

ระยะยกฝาครอบ (Exploded View): 25 mm

ความยาวคลื่นลำแสง (Laser Spectrum):

465 nm (N) 525 nm (P) 625 nm (K) White (Calib)

การแสดงผลชิ้นส่วน 3D

ฝาปิด (Lid) คิวเวตต์ (Cuvette) ลำแสง (Ray) เซนเซอร์ (PCBs)

วิศวกรรมโมเดล 3D (Workstation & Chassis)

🌟 SpectorV5 Console 🔒 SpectorV5 Lid 📦 SpectorV4 Shell 🕸️ โครงลวด ✂️ ผ่าครึ่ง 🔄 หมุนรอบตัว 🎯 รีเซ็ตมุม

สเปกวิศวกรรมทัศนศาสตร์:

- แนวแกนแสงตรง: สูง 15.0 mm จากก้นคิวเวตต์
- ช่องจำกัดลำแสงคู่ (Collimators): Ø 3.0 mm
- ช่องคิวเวตต์: 12.75 x 12.75 mm (Path 10 mm)
- ขอบฝาประกบ: Labyrinth Seal ป้องกันแสง 100%

3D Real-Time Physics Engine Active | Coaxial Optical Axis Collinear

ลากและวางไฟล์ .STL ลงในหน้านี้เพื่อสลับโมเดลได้ทันที

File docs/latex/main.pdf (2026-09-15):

# มหาวิทยาลัยราชภัฏรำไพพรรณี

## คณะวิทยาศาสตร์และเทคโนโลยี สาขาวิชาฟิ สิกส์

### หน่วยวิจัยเกษตรดิจิทัล JC_AI_SciRBRU (Digital Agriphysics & AI Research Unit)

# คู่มือการประกอบ ติดตั

้

# ง และใช้งาน

## เครื่องสเปกโทรโฟโตมิเตอร์ตรวจวัดธาตุอาหารหลักในดิน และสมบัติเชิงแสงของของเหลว

## NPK Level Meter 1.02 & Liquid Optics Analyzer


## ผู้ช่วยศาสตราจารย์ ดร.ชีวะ ทัศนา และคณะ

เอกสารทางวิชาการและคู่มือการวิจัยและพัฒนาสิ่งประดิษฐ์ กันยายน 2569

เอกสารคู่มือการประกอบ ติดตั้

ง และใช้งานเครื่องสเปกโทรโฟโตมิเตอร์ตรวจวัด ธาตุอาหารหลักในดินและสมบัติเชิงแสงของของเหลว (NPK Level Meter 1.02 & Liquid Optics Analyzer) เล่มนี้จัดทำขึ้นเพื่อเป็ นคู่มือวิชาการและแนวทางการปฏิบัติการเชิงลึก สำหรับนักวิจัย คณาจารย์ นักศึกษา และเกษตรกรผู้สนใจนวัตกรรมเกษตรแม่นยำ (Precision Agriculture) โดยเฉพาะการบริหารจัดการธาตุอาหารในสวนทุเรียนแปลงใหญ่ในเขต ภาคตะวันออกของประเทศไทย
ระบบตรวจวัดนี้
ได้รับการออกแบบและพัฒนาขึ้นภายใต้แนวคิดการประมวลผล บนชิปสมบูรณ์ (Edge-Only Architecture) โดยผสานสถาปั ตยกรรมไมโครคอนโทรลเลอร์ สมรรถนะสูง Microchip ATSAMD51 ARM Cortex-M4F ร่วมกับ เซนเซอร์วัดค่าสีดิจิทัล TCS34725 และ แหล่ง กำเนิด แสง สเปกตรัม หลาย ช่วง คลื่น NeoPixel WS2812B ทำให้ สามารถวิเคราะห์ธาตุอาหารดิน ไนโตรเจน (N) ฟอสฟอรัส (P) โพแทสเซียม (K) และความ เป็ นกรด-ด่างดิน (Soil pH) ได้อย่างรวดเร็ว พร้อมทั้
งรองรับการคำนวณ 3 โหมด คือ โครง ข่ายประสาทเทียม TinyML Deep Learning, สมการพหุนามสากล, และระบบสร้างเส้นโค้ง มาตรฐานสดในตัวเครื่อง (In-Situ Standard Curve Wizard) ที่คำนวณความชัน จุดตัด R² LOD และ LOQ ตามเกณฑ์สากลของ IUPAC ตลอดจนสถาปั ตยกรรม 8 หน้าจอ (8-Screen Carousel UI) ที่มีระบบสลับความยาวคลื่นแสงอัตโนมัติ (Auto-Wavelength Switching) และการวิเคราะห์ดัชนีหักเหของแสง (n) ความหนาแน่น (ρ) ปริมาณของแข็ง (◦Bx) และ ระดับความขุ่นของตัวอย่างของเหลวทางการเกษตร เนื้อหาภายในคู่มือเล่มนี้แบ่งออกเป็ น 5 บทหลัก และ 2 ภาคผนวก ประกอบด้วย
1. บทที่ 1 บทนำและหลักการฟิ สิกส์เชิงแสง อธิบายทฤษฎีกฎของเบียร์และแลมเบิร์ต สเปกตรัมการดูดกลืนแสง และแบบจำลองมาตรวิทยาของเหลว
2. บทที่ 2 การออกแบบและประกอบชิ้นส่วนฮาร์ดแวร์แสดงรายการอุปกรณ์ แผนผัง การเชื่อมต่อวงจร และขั้นตอนการประกอบเชิงกล
3. บทที่3 การติดตั้งเฟิ ร์มแวร์และการตั้งค่าซอฟต์แวร์แนะนำไลบรารีที่จำเป็ น การตั้ ง
ค่าฟอนต์ และการคอมไพล์ผ่าน Arduino CLI
4. บทที่4 คู่มือการปฏิบัติการและแบบจำลองการเทียบมาตรฐาน นำเสนอการทำงาน ของระบบ 8 หน้าจอ (8-Screen Carousel UI) ระบบเปลี่ยนความยาวคลื่นอัตโนมัติ ขั้น ตอนการวัดดินและของเหลว และสถิติการสร้างกราฟมาตรฐาน

i

ii

5. บทที่5 การบำรุงรักษาและการแก้ไขปั ญหา รวบรวมแนวทางการดูแลรักษาอุปกรณ์ และการแก้ไขข้อขัดข้องที่อาจเกิดขึ้นในภาคสนาม
6. ภาคผนวก รวบรวมตารางค่าดัชนีหักเหและความหนาแน่นมาตรฐาน ICUMSA และ ข้อมูลจำเพาะเชิงสถาปั ตยกรรมของ Wio Terminal

คณะผู้จัดทำหวังเป็ นอย่างยิ่งว่า คู่มือวิชาการเล่มนี้จะเป็ นประโยชน์ต่อการนำไป ประยุกต์ ใช้งานจริงในภาคสนาม การจัดการ เรียนการสอนในห้องปฏิบัติการฟิ สิกส์และ เครื่องมือ วัด และ เป็ นรากฐาน ในการพัฒนา เทคโนโลยี เกษตรอัจฉริยะของประเทศไทย สืบไป

ผู้ช่วยศาสตราจารย์ ดร.ชีวะ ทัศนา และคณะ หน่วยวิจัยเกษตรดิจิทัล JC_AI_SciRBRU (Digital Agriphysics & AI Research Unit) สาขาวิชาฟิ สิกส์ คณะวิทยาศาสตร์และเทคโนโลยี มหาวิทยาลัยราชภัฏรำไพพรรณี กันยายน 2569

คำนำ | i
สารบัญ | iii
สารบัญภาพ | vi
สารบัญตาราง | vii
1 บทนำและหลักการฟิ สิกส์เชิงแสง | 1
2 การออกแบบและประกอบชิ้นส่วนฮาร์ดแวร์ | 6

iii

สารบัญ | iv
3 การติดตั้งเฟิ ร์มแวร์และการตั้งค่าซอฟต์แวร์ | 12

3.3 ระบบเครือข่าย Wi-Fi และสถาปั ตยกรรม Embedded JSON REST Server 14 3.4 คำสั่

4 คู่มือการปฏิบัติการและแบบจำลองการเทียบมาตรฐาน | 17

4.1 ระบบควบคุมหน้าจอและการนำทาง 8 หน้าจอ (8-Screen Carousel UI) . 19

4.5 การวิเคราะห์สมบัติเชิงทัศนศาสตร์และความหนาแน่นของของเหลว . . . 22

5 การบำรุงรักษาและการแก้ไขปั ญหา | 25

สารบัญ | v
ก ตารางค่าดัชนีหักเหและความหนาแน่นของสารละลายมาตรฐาน | 30
ข ข้อมูลจำเพาะเชิงเทคนิคและสถาปั ตยกรรมฮาร์ดแวร์ Wio Terminal | 31
เอกสารอ้างอิง | 32
ประวัติผู้เขียน | 33

1.1 เครื่องสเปก โทร โฟ โตมิเตอร์ตรวจวัดธาตุอาหารหลัก ในดิน NPK Level

vi

4.1 สถาปั ตยกรรมหน้าจอแสดงผล 8 หน้าจอ (8-Screen Carousel UI) . . . . 19 4.2 ฟั งก์ชันการควบคุมการนำทางและคำสั่

ก.1 ค่ามาตรฐานดัชนีหักเหและความหนาแน่นของสารละลายตามเกณฑ์ ICUMSA 30

ข.1 ข้อมูลจำเพาะเชิงเทคนิคของระบบประมวลผล Wio Terminal ATSAMD51 31

vii

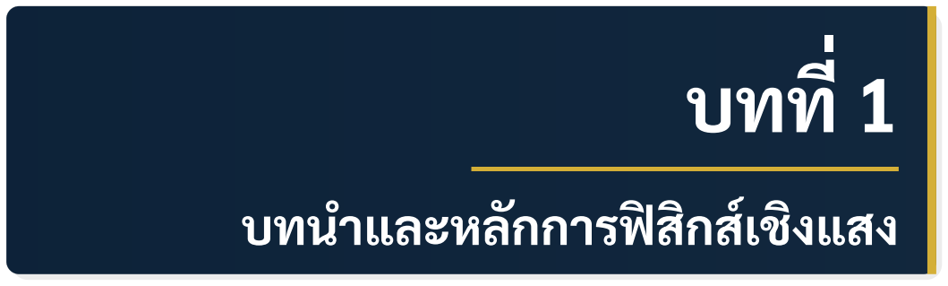
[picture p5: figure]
บทที; บทนำและหลักการฟิ สิกส์เชิงแสง

## แผนบริหารการสอนประจำบทที่1

หัวข้อเนื้อหาประจำบท

1. ความสำคัญของการตรวจวัดธาตุอาหารดินในการเกษตรแม่นยำ
2. หลักการทางทัศนศาสตร์ฟิ สิกส์และกฎของเบียร์และแลมเบิร์ต
3. การจำแนกแถบสเปกตรัมแสงสำหรับการตรวจ วัดธาตุ ไนโตรเจน ฟอสฟอรัส และโพแทสเซียม
4. ทฤษฎีการลดทอนแสงและความสัมพันธ์กับดัชนีหักเหและความหนาแน่นของ ของเหลว

วัตถุประสงค์เชิงพฤติกรรม
1. อธิบายหลักการทางฟิ สิกส์ของการดูดกลืนแสงตามกฎของเบียร์และแลมเบิร์ต ได้อย่างถูกต้อง
2. จำแนกความยาวคลื่นที่
เหมาะสมในการทำปฏิกิริยากับสารละลายธาตุอาหาร ดินได้อย่างสมบูรณ์
3. อธิบายความสัมพันธ์ระหว่างการลดทอนแสงกับดัชนีหักเหและความหนาแน่น ของของเหลวได้อย่างถูกต้อง

กิจกรรมการเรียนการสอน
1. การ บรรยาย เชิง ทฤษฎี ประกอบ การ ฉาย สื่อ แอนิเมชัน การ แผ่ และ ดูด กลืน คลื่นแม่เหล็กไฟฟ้ า
2. การ สาธิต การ ทำงาน ของ เครื่อง สเปก โทร โฟ โต มิเตอร์ ตรวจ วัด สารละลาย

1

2

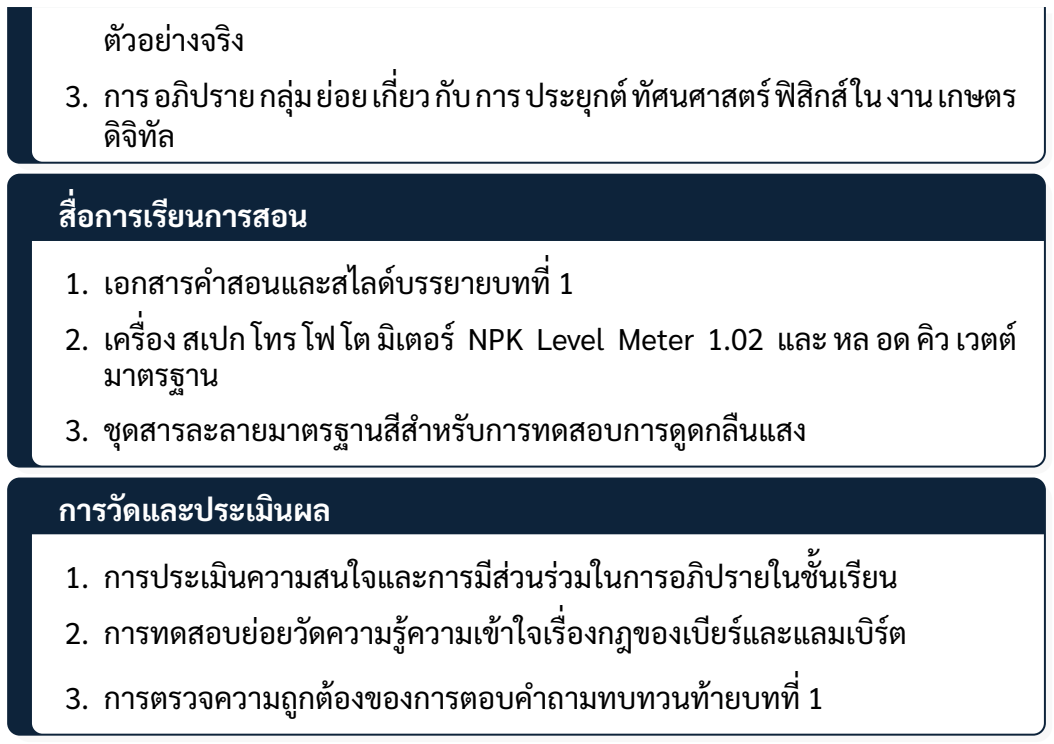
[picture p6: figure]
ตัวอย่างจริง; สื่อการเรียนการสอน; 1. เอกสารคำสอนและสไลด์บรรยายบทที่ 1; มาตรฐาน; การวัดและประเมินผล

3. การ อภิปราย กลุ่ม ย่อย เกี่ยว กับ การ ประยุกต์ ทัศนศาสตร์ ฟิ สิกส์ ใน งาน เกษตร
2. เครื่อง สเปก โทร โฟ โต มิเตอร์ NPK Level Meter 1.02 และ หล อด คิว เวตต์
3. ชุดสารละลายมาตรฐานสีสำหรับการทดสอบการดูดกลืนแสง
1. การประเมินความสนใจและการมีส่วนร่วมในการอภิปรายในชั้นเรียน
2. การทดสอบย่อยวัดความรู้ความเข้าใจเรื่องกฎของเบียร์และแลมเบิร์ต
3. การตรวจความถูกต้องของการตอบคำถามทบทวนท้ายบทที่ 1

1.1. ความสำคัญของการตรวจวัดธาตุอาหารดินในการเกษตรแม่นยำ | 3

## 1.1 ความสำคัญของการตรวจวัดธาตุอาหารดินในการเกษตร แม่นยำ

การตรวจวัดปริมาณธาตุอาหารหลักในดินอันประกอบด้วยไนโตรเจน ฟอสฟอรัส และ โพแทสเซียม หรือ NPK มีความสำคัญอย่างยิ่งต่อการบริหารจัดการธาตุอาหารพืช
ใน การเกษตร แม่นยำ (Precision Agriculture) โดย เฉพาะ ใน พื้นที่ปลูก ไม้ ผล เศรษฐกิจ เช่น ทุเรียนแปลง ใหญ่ การตรวจวัด ในภาคสนามที่ต้องการความรวดเร็วและแม่นยำสูง สามารถ ดำเนิน การ ได้ ด้วย เทคนิค การ ดูด กลืน แสง เชิง สเปกตรัม (Optical Absorption Spectroscopy)

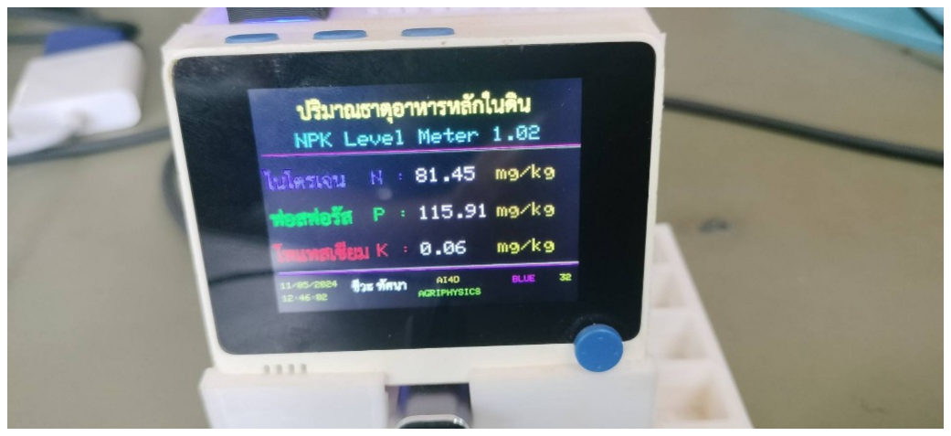
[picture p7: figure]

ภาพที่1.1 เครื่องสเปกโทรโฟโตมิเตอร์ตรวจวัดธาตุอาหารหลักในดิน NPK Level Meter 1.02

## 1.2 กฎของเบียร์และแลมเบิร์ต

เมื่อลำแสงเอกรงค์ (Monochromatic Light) หรือแสงที่มีความยาวคลื่นจำเพาะ ส่องผ่านสารละลายตัวอย่างดินที่ผ่านกระบวนการทำปฏิกิริยาเกิดสี ความเข้มของแสงที่ ทะลุผ่านจะลดลงตามความเข้มข้นของสารละลายและความหนาของชั้นสารละลายตาม ความสัมพันธ์

A(λ) = − log10 (
I(λ) − Idark

I0(λ) − Idark)
= ε(λ) · b · C | (1.1)

กำหนดให้
- A(λ) แทนค่าการดูดกลืนแสง (Absorbance) ณ ความยาวคลื่น λ
- I0(λ) แทนความเข้มแสงเริ่มต้นที่ส่องผ่านสารละลายแบลงก์ (Blank Reference)
- I(λ) แทนความเข้มแสงที่ทะลุผ่านสารละลายตัวอย่าง (Sample Transmitted Intensity)

1.3. การจำแนกความยาวคลื่นสำหรับการวัด NPK | 4
- Idark แทนสัญญาณกระแสมืดของเซนเซอร์ขณะดับไฟ (Dark Current)
- ε(λ) แทนสัมประสิทธิ์การดูดกลืนแสงโมลาร์ (Molar Absorptivity)
- b แทนความยาวของทางเดินแสงในคิวเวตต์ มีค่าเท่ากับ 1.0 เซนติเมตร
- C แทนความเข้มข้นของธาตุอาหารในสารละลาย มีหน่วยเป็ นมิลลิกรัมต่อกิโลกรัม (mg/kg)

## 1.3 การจำแนกความยาวคลื่นสำหรับการวัด NPK

ระบบสเปกโทรโฟโตมิเตอร์เครื่องนี้

ใช้แหล่งกำเนิดแสงแบบหลายความยาวคลื่น ผ่านโมดูลไดโอด เปล่งแสงหลายสีดิจิทัล WS2812B ร่วมกับ เซนเซอร์วัดค่าสีแบบดิจิทัล TCS34725 ซึ่

งสามารถแยกแยะช่องสัญญาณแสงตามความยาวคลื่นหลักได้ดังนี้

1. แสงสีน้ำเงิน (Blue Spectrum ความยาวคลื่น 465 นาโนเมตร) ใช้สำหรับการตรวจ
วัดความเข้มข้นของธาตุไนโตรเจน (Nitrogen หรือ N) ซึ่ | งทำปฏิกิริยากับน้ำยาทดสอบ
เกิดสารประกอบสีส้มอมน้ำตาล
2. แสงสีฟ้ าอมเขียว (Cyan Spectrum ความยาวคลื่น 500 นาโนเมตร) ใช้สำหรับการ วิเคราะห์สารประกอบอินทรีย์และการดูดกลืนแสงช่วงกลาง
3. แสงสีเขียว (Green Spectrum ความยาวคลื่น 525 นาโนเมตร) ใช้สำหรับการตรวจ
วัด ความ เข้ม ข้น ของ ธาตุ ฟอสฟอรัส (Phosphorus หรือ P) ซึ่ | งทำปฏิกิริยา กับน้ำยา
ทดสอบเกิดสารประกอบเชิงซ้อนสีน้ำเงินโมลิบดีนัม
4. แสงสีเหลือง (Yellow Spectrum ความยาวคลื่น 590 นาโนเมตร)ใช้สำหรับการตรวจ วัดค่าความขุ่นและอนุภาคแขวนลอยในสารละลาย
5. แสงสีแดง (Red Spectrum ความยาวคลื่น 625 นาโนเมตร) ใช้สำหรับการตรวจวัด
ความเข้มข้นของธาตุโพแทสเซียม (Potassium หรือ K) ซึ่ | งทำให้เกิดความขุ่นและการ
สะท้อนแสงของตะกอนเตตระฟี นิลบอเรต
6. แสงสีขาว (White Spectrum ความยาวคลื่นครอบคลุม 400 ถึง 700 นาโนเมตร) ใช้ สำหรับการเทียบมาตรฐานศูนย์ (Blank Calibration) และการตรวจวัดค่าความขุ่นรวม ของสารละลายดิน

## 1.4 การวิเคราะห์สมบัติเชิงทัศนศาสตร์และมาตรวิทยาของเหลว

นอกเหนือจากการตรวจวัดธาตุอาหารในดินแล้ว ระบบยังได้รับการพัฒนาขยาย ขีดความสามารถสู่การเป็ นเครื่องตรวจวิเคราะห์สมบัติเชิงแสงและกายภาพของตัวอย่าง ของเหลวทางการเกษตร (Liquid Optics & Metrology) เช่น น้ำชลประทาน น้ำหมักชีวภาพ

1.4. การวิเคราะห์สมบัติเชิงทัศนศาสตร์และมาตรวิทยาของเหลว | 5

และสารละลายธาตุอาหารพืช โดยอาศัยหลักการความสัมพันธ์ระหว่างการลดทอนแสง (Optical Attenuation) กับดัชนีหักเหของแสง (Refractive Index, n) และความหนาแน่น ของของเหลว (ρ) ตามมาตรฐานสากล ICUMSA และทฤษฎี Lorentz-Lorenz & Gladstone-Dale

n = 1.3330 + 0.00143 · (Brix) + 0.0000045 · (Brix)
2
| (1.2)

ρ = 0.9982 + 0.00385 · (Brix) + 0.000012 · (Brix)
2

(g/cm³

) (1.3)

โดยที่น้ำกลั่นบริสุทธิ์มีค่าดัชนีหักเห n = 1.3330 และความหนาแน่น ρ = 0.9982 g/cm³ ที่อุณหภูมิห้อง 20 องศาเซลเซียส

## บทสรุปประจำบทที่1

การตรวจวัดธาตุอาหารหลักในดิน NPK และสมบัติของเหลวด้วยเทคนิคสเปกโทร โฟโตเมตรี อาศัยหลักการการลดทอนของความเข้มแสงเมื่อส่องผ่านตัวกลางตามกฎของ เบียร์และแลมเบิร์ต แหล่งกำเนิดแสงดิจิทัล WS2812B ร่วมกับเซนเซอร์ TCS34725 ช่วยให้ สามารถเลือกปล่อยแสงความยาวคลื่นจำเพาะ 465, 500, 525, 590 และ 625 นาโนเมตร ได้อย่างแม่นยำ พร้อมทั้

งสามารถประเมินสมบัติเชิงกายภาพของของเหลว ทั้ | งดัชนีหักเห
ความหนาแน่น และระดับความเข้มข้นสารละลาย ได้อย่างมีประสิทธิภาพบนอุปกรณ์พก พาขนาดกะทัดรัด

## คำถามทบทวนท้ายบทที่1

1. จงอธิบายหลักการทางฟิ สิกส์ของกฎของเบียร์และแลมเบิร์ต และระบุข้อจำกัดในการนำ กฎนี้

ไปประยุกต์ใช้กับสารละลายตัวอย่างดินที่มีความขุ่นสูง

2. เหตุใดการตรวจวัดธาตุไนโตรเจน (N) และฟอสฟอรัส (P) จึงต้องใช้ความยาวคลื่นแสง ที่แตกต่างกัน จงอธิบายความสัมพันธ์กับสารประกอบเชิงซ้อนที่
เกิดขึ้น
3. สัญญาณกระแสมืด (Dark Current) คืออะไร และเหตุใดระบบเฟิ ร์มแวร์จึงต้องทำการ ดับไฟเพื่อวัดกระแสมืดก่อนทำการกวาดสเปกตรัมแสงทุกครั้
ง
4. จงอธิบายความสัมพันธ์ระหว่างค่าการดูดกลืนแสงเฉลี่ย (Amean) ดัชนีหักเห (n) และ ความหนาแน่น (ρ) ของของเหลวตามมาตรฐาน ICUMSA

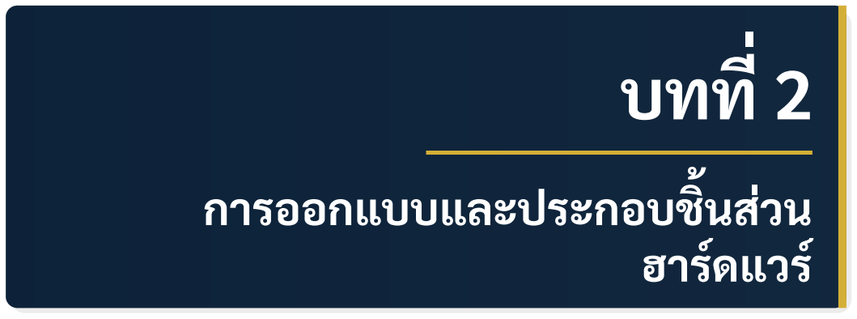
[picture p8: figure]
บทที; การออกแบบและประกอบชิ; ้ นส่วน ฮาร์ดแวร์

## แผนบริหารการสอนประจำบทที่2

หัวข้อเนื้อหาประจำบท

1. สถาปั ตยกรรมฮาร์ดแวร์และคุณสมบัติของไมโครคอนโทรลเลอร์ ATSAMD51
2. รายการอุปกรณ์และโมดูลตรวจวัดแสง TCS34725 ร่วมกับหลอดไฟ WS2812B
3. การออกแบบทางเดินแสงของช่องใส่คิวเวตต์เพื่อลดการสะท้อนและการกระเจิง
4. ขั้นตอนการประกอบกลไกและการต่อขาสัญญาณดิจิทัล

วัตถุประสงค์เชิงพฤติกรรม
1. ระบุหน้าที่และตำแหน่งของขาสัญญาณควบคุมในระบบสเปกโทรโฟโตมิเตอร์ ได้อย่างถูกต้อง
2. อธิบายหลักการจัดวางแนวแกนแสงระหว่างแหล่งกำเนิด หลอดคิวเวตต์ และ เซนเซอร์ได้อย่างสมบูรณ์
3. ปฏิบัติ การ ประกอบ และ ทดสอบ การ เชื่อม ต่อ วงจร ฮาร์ดแวร์ ได้ อย่าง ถูก ต้อง ปลอดภัย

กิจกรรมการเรียนการสอน
1. การบรรยายและสาธิตการเชื่อมต่อสายสัญญาณผ่านพอร์ต Grove
2. ปฏิบัติการประกอบชิ้นส่วนฮาร์ดแวร์ลงในกล่องบรรจุ 3D Printed Enclosure

6

7

3. การตรวจสอบความถูกต้องของระบบไฟฟ้ าและสัญญาณ I2C ก่อนการจ่ายไฟ

สื่อการเรียนการสอน
1. บอร์ด Seeed Studio Wio Terminal พร้อมสายเชื่อมต่อ Grove
2. โมดูลเซนเซอร์ Adafruit TCS34725 และโมดูลไฟ Grove NeoPixel WS2812B
3. ชุดโครงสร้างกล่องบรรจุ 3 มิติและแท่นยึดคิวเวตต์ขนาด 10 มิลลิเมตร

การวัดและประเมินผล
1. การประเมินทักษะการประกอบวงจรและการจัดสายสัญญาณอย่างเป็ นระเบียบ
2. การทดสอบการตรวจพบอุปกรณ์ I2C ผ่านโปรแกรมตรวจสอบที่อยู่บัส
3. การตรวจความถูกต้องของการตอบคำถามทบทวนท้ายบทที่ 2

2.1. รายการอุปกรณ์และโมดูลฮาร์ดแวร์ | 8

## 2.1 รายการอุปกรณ์และโมดูลฮาร์ดแวร์

อุปกรณ์ที่

ใช้ในการประกอบและสร้าง เครื่องสเปกโทรโฟโตมิเตอร์ประกอบด้วย รายการดังแสดงในตารางที่ 2.1

ตารางที่2.1 รายการอุปกรณ์และโมดูลฮาร์ดแวร์

อุปกรณ์ | รุ่นหรือรหัสสินค้า | บทบาทหน้าที่
ในระบบ
บอร์ดประมวลผล Seeed Studio Wio Terminal

ไมโคร คอนโทรลเลอร์ ATSAMD51 พร้อมจอ LCD 2.4 นิ้ว
เซนเซอร์ ตรวจ วัด
แสง

Adafruit TCS34725 เซนเซอร์ตรวจวัดแสงสีและค่าความ สว่างแบบ I2C
แหล่งกำเนิดแสงสี Grove | RGB | LED
(WS2812B)

ไดโอดเปล่งแสงควบคุมสีแบบดิจิทัล ความยาวคลื่นแม่นยำ
ช่อง ใส่ หลอด
ทดลอง

Cuvette Holder 10 mm แท่นยึดหลอดคิวเวตต์มาตรฐานทาง เดินแสง 10 มิลลิเมตร
สายเชื่อมต่อข้อมูล Grove 4-Pin Cable สายส่ง สัญญาณ ดิจิทัล และ สาย จ่าย พลังงานไฟฟ้ า
การ์ด หน่วย ความ
จำ

microSD Card Class 10 อุปกรณ์ บันทึก ผล การ วัด ลง ไฟล์ ข้อมูล 4 รูป แบบ (NPK.csv, SPEC-TRUM.csv, CALIB_LOG.csv, LIQ-UID_LOG.csv)
โครงสร้างตัวเครื่อง 3D Printed Enclosure กล่อง บรรจุ อุปกรณ์ ภายนอก ออกแบบด้วยเส้นใย PLA+

## 2.2 แผนภาพการต่อวงจรและขาสัญญาณ

การเชื่อมต่อสัญญาณระหว่างบอร์ด Wio Terminal กับโมดูลเซนเซอร์และแหล่ง กำเนิดแสง แสดงรายละเอียดตามตารางที่ 2.2

2.3. การออกแบบทางเดินแสงและกล่องบรรจุ 3 มิติ | 9

ตารางที่2.2 การกำหนดขาสัญญาณและการเชื่อมต่ออุปกรณ์

อุปกรณ์ภายนอก พอร์ต Wio Terminal

ขา สัญญาณ
ไมโคร

คำอธิบายการเชื่อมต่อ

TCS34725 (SDA) Grove พอร์ตขวา ขา SDA (PA17) ส่ง สัญญาณ ข้อมูล I2C บัสความเร็ว 100 kHz
TCS34725 (SCL) Grove พอร์ตขวา ขา SCL (PA16) ส่งสัญญาณนาฬิกา I2C บัสความเร็ว 100 kHz
TCS34725 (VCC) Grove พอร์ตขวา ขา 3V3 หรือ 5V แหล่ง จ่าย พลังงาน ไฟฟ้ ากระแส ตรง 3.3
โวลต์
TCS34725
(GND)
| Grove พอร์ตขวา ขา GND | กราวด์ร่วมของระบบ
RGB LED (DIN) | Grove พอร์ตซ้าย ขา D0 (PB08) | ขา สัญญาณ ข้อมูล ควบคุมหลอด NeoPixel WS2812B
RGB LED (VCC) | Grove พอร์ตซ้าย ขา 5V | จ่าย แรง ดัน ไฟฟ้ า เลี้ยง
| | หลอดไฟ 5 โวลต์
RGB LED (GND) Grove พอร์ตซ้าย ขา GND | กราวด์ร่วมของหลอดไฟ
ปุ่ มกด A | ด้านบนตัวเครื่อง WIO_KEY_A (28) ปุ่ มด้านขวาสุด ควบคุม
| | การเปิ ดปิ ดแสงสีแดง
ปุ่ มกด B | ด้านบนตัวเครื่อง WIO_KEY_B (29) ปุ่ ม ตรง กลาง ควบคุม
| | การเปิ ดปิ ดแสงสีเขียว
ปุ่ มกด C | ด้านบนตัวเครื่อง WIO_KEY_C (30) ปุ่ มด้านซ้ายสุด ควบคุม
| | การเปิ ดปิ ดแสงสีน้ำเงิน
จอยสติ๊กกลาง | ด้านหน้าตัวเครื่อง WIO_5S_PRESS
| (35) | กดลงตรงกลาง ควบคุม
| | การเปิ ดปิ ดแสงสีขาว

## 2.3 การออกแบบทางเดินแสงและกล่องบรรจุ 3 มิติ

กล่องบรรจุอุปกรณ์ภายนอก (Enclosure) และแท่นยึดคิวเวตต์ได้รับการขึ้นรูปด้วย เครื่องพิมพ์สามมิติ (3D Printing) โดยใช้วัสดุเส้นใย PLA+ สีดำด้าน (Matte Black) เพื่อ ลดการสะท้อนแสงภายในห้องวัด (Internal Reflection Reduction) โดยมีคุณลักษณะทาง ทัศนศาสตร์ที่สำคัญ

- แนวแกนแสงตรง (Coaxial Optical Path): กึ่
งกลางหลอดไฟ WS2812B ช่องคิวเวตต์ และเซนเซอร์ TCS34725 อยู่ในระดับความสูงเดียวกันที่ 15.0 มิลลิเมตรจากฐาน

2.4. ขั้นตอนการประกอบชิ้นส่วนกลไก | 10
- ช่องจำกัดลำแสง (Collimating Aperture): ขนาดเส้นผ่านศูนย์กลาง 3.0 มิลลิเมตร ติดตั้
งระหว่างหลอด LED กับผิวคิวเวตต์ เพื่อให้ได้ลำแสงขนานที่ตั้ | งฉากกับผนังคิวเวตต์
- ฝาครอบกันแสงภายนอก (Light-Tight Lid): มีขอบประกบแบบเขี้ยวซ้อน (Baffle Joint) ป้ องกันแสงรอบข้าง (Ambient Light Stray) เล็ดลอด เข้าสู่ เซนเซอร์ได้อย่าง สมบูรณ์

## 2.4 ขั

้

## นตอนการประกอบชิ

้

## นส่วนกลไก

การประกอบอุปกรณ์ลงในกล่องบรรจุ 3D Printed Enclosure มีขั้นตอนดังต่อไปนี้

1. นำแท่นยึดหลอดคิวเวตต์ (Cuvette Holder) ติดตั้
| งเข้ากับฐานล่างของกล่อง โดยหัน
ด้านช่องส่องแสงให้ตรงกับตำแหน่งติดตั้
งโมดูลหลอดไฟและเซนเซอร์
2. ติดตั้
งโมดูลหลอดไฟ Grove RGB LED เข้ากับด้านข้างช่องคิวเวตต์ โดยให้ผิวหน้าของ หลอด LED ขนานกับผนังคิวเวตต์และกั้นแสงรบกวนจากภายนอก
3. ติดตั้
งโมดูลเซนเซอร์ TCS34725 ในตำแหน่งตรงข้ามกับหลอด LED ในแนวแกนแสง เดียวกัน เพื่อให้รับลำแสงที่ทะลุผ่านหลอดคิวเวตต์ได้อย่างสมบูรณ์
4. เสียบสาย Grove 4-Pin จากหลอด LED เข้าสู่พอร์ต Grove ด้านซ้าย (D0) ของบอร์ด Wio Terminal
5. เสียบสาย Grove 4-Pin จาก เซนเซอร์ TCS34725 เข้าสู่พอร์ต Grove ด้านขวา (I2C) ของบอร์ด Wio Terminal
6. ประกอบบอร์ด Wio Terminal เข้ากับฝาครอบด้านหน้า ขันสกรูยึดให้แน่นหนา และ ตรวจเช็คการขยับของปุ่ มกด A, B, C และจอยสติ๊กด้านหน้าให้เคลื่อนไหวได้อย่างอิสระ

## บทสรุปประจำบทที่2

การออกแบบโครงสร้างฮาร์ดแวร์ของ เครื่องสเปกโทรโฟโตมิเตอร์คำนึงถึงความ แม่นยำทางทัศนศาสตร์และความสะดวกในการพกพา การใช้พอร์ต Grove อำนวยความ สะดวกในการเชื่อมต่อเซนเซอร์ I2C และหลอดดิจิทัล NeoPixel อย่างแน่นหนา ในขณะที่ ห้องวัดแสงที่พิมพ์ด้วยเส้นใยสีดำด้านพร้อมช่องจำกัดลำแสงช่วยลดสัญญาณรบกวนและ แสงกระเจิง ส่งผลให้สัญญาณการวัดมีความเสถียรและทำซ้ำได้สูง

2.4. ขั้นตอนการประกอบชิ้นส่วนกลไก | 11

## คำถามทบทวนท้ายบทที่2

1. เหตุใดการออกแบบแท่นยึดคิวเวตต์จึงต้องใช้วัสดุสีดำด้าน และหากใช้วัสดุสีขาวสะท้อน แสงจะส่งผลกระทบต่อค่าการดูดกลืนแสงอย่างไร
2. สัญญาณ นาฬกา I2C ที ิ

่ความเร็ว 100 kHz เหมาะ สม กับ การ อ่าน ค่า จาก เซนเซอร์ TCS34725 หรือไม่ เพราะเหตุใด
3. จงอธิบายบทบาทของช่องจำกัดลำแสง (Collimating Aperture) ที่อยู่ระหว่างหลอด ไฟ LED กับคิวเวตต์
4. หาก เซนเซอร์ TCS34725 ไม่อยู่ ในแนวแกน เดียวกับหลอด LED จะ เกิดความคลาด เคลื่อนเชิงแสงในลักษณะใด

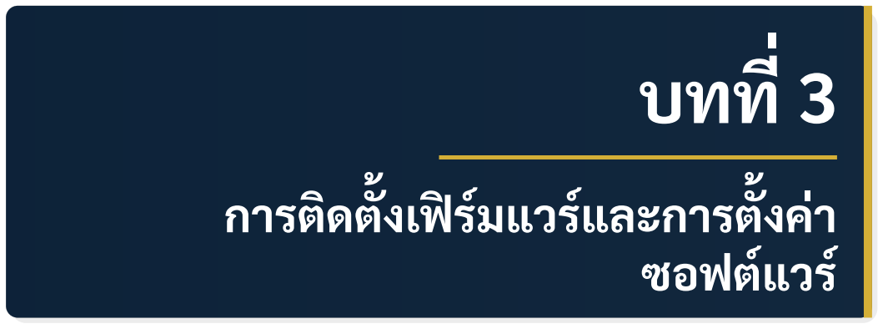
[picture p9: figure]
บทที; การติดตั; ้ งเฟิ ร์มแวร์และการตั; ้ งค่า ซอฟต์แวร์

## แผนบริหารการสอนประจำบทที่3

หัวข้อเนื้อหาประจำบท

1. สถาปั ตยกรรมเฟิ ร์มแวร์แบบโมดูลาร์บนชิป ATSAMD51 ARM Cortex-M4F
2. การติดตั้
งและการกำหนดค่าไลบรารีระบบควบคุมจอภาพและเซนเซอร์
3. สถาปั ตยกรรมการเชื่อมต่อเครือข่ายไร้สาย Wi-Fi และ Embedded JSON REST Server
4. การคอมไพล์โปรแกรมผ่าน Arduino CLI และเทคนิคการอัปโหลดเฟิ ร์มแวร์
5. การกู้คืนระบบผ่านโหมด Bootloader และการจัดการหน่วยความจำ Flash

วัตถุประสงค์เชิงพฤติกรรม
1. อธิบายโครงสร้างสถาปั ตยกรรมซอฟต์แวร์และการทำงานร่วมกันของแต่ละเอน จินได้อย่างถูกต้อง
2. ติดตั้

งไลบรารีที่จำเป็ นและแก้ไขคอนฟิ กูเรชันของบอร์ด Wio Terminal ได้อย่าง สมบูรณ์
3. กำหนดค่าการเชื่อมต่อเครือข่าย Wi-Fi ทั้
งโหมด Station และ SoftAP ได้อย่าง ถูกต้อง
4. คอมไพล์โปรแกรมและกู้คืนบอร์ดผ่านโหมด Bootloader เมื่อเกิดข้อขัดข้องได้ อย่างชำนาญ

12

13

วิธีสอนและกิจกรรมการเรียนการสอน
1. การบรรยายเชิงวิชาการประกอบสไลด์และไดอะแกรมการไหลของข้อมูล (Data Flow Diagram)
2. การฝึ กปฏิบัติการ เขียนคำสั่
งคอมไพล์ผ่านระบบ Command Line Interface (Arduino CLI)
3. กิจกรรม การ ทดลอง เชื่อม ต่อ บอร์ด Wio Terminal กับ เครือ ข่าย Wi-Fi และ ทดสอบคำสั่
ง REST API
4. การจำลองสถานการณ์พอร์ตสื่อสารขัดข้องและฝึ กปฏิบัติการกู้คืนด้วยระบบ Double Touch Reset

สื่อการเรียนการสอน
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

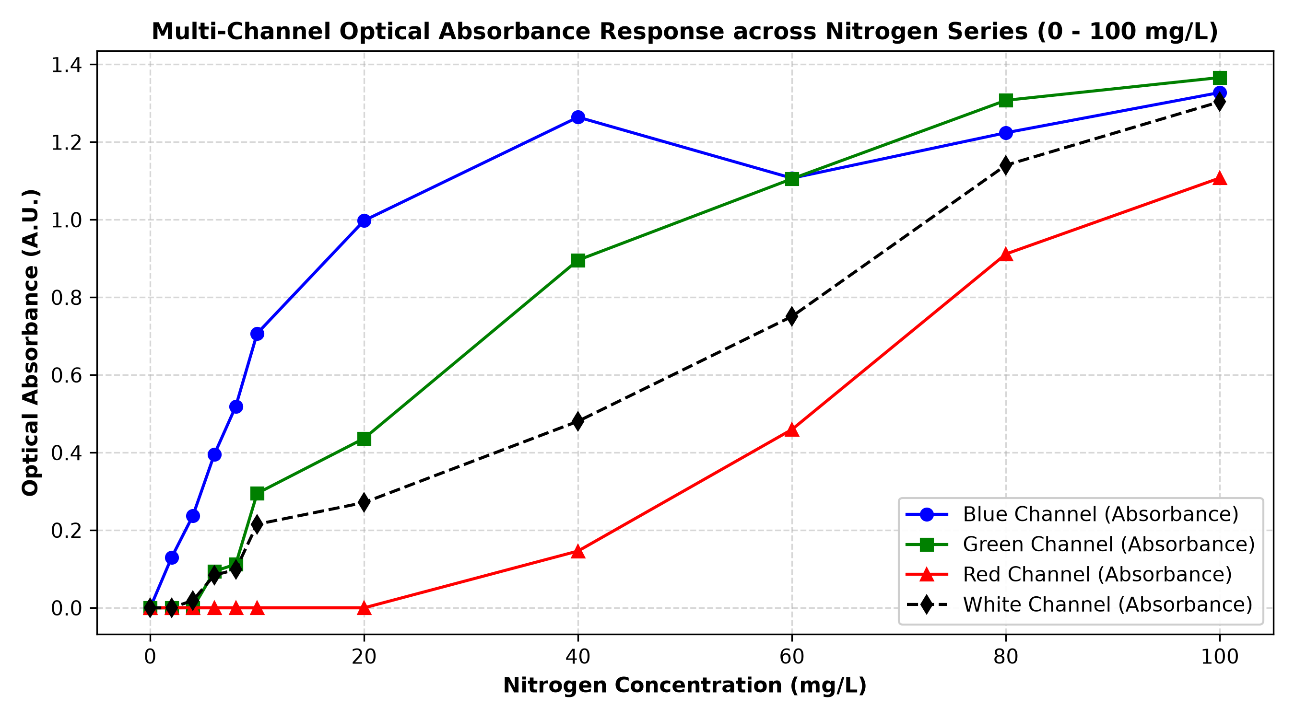
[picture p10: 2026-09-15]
docs/images/spectral_response_multi_channel.png

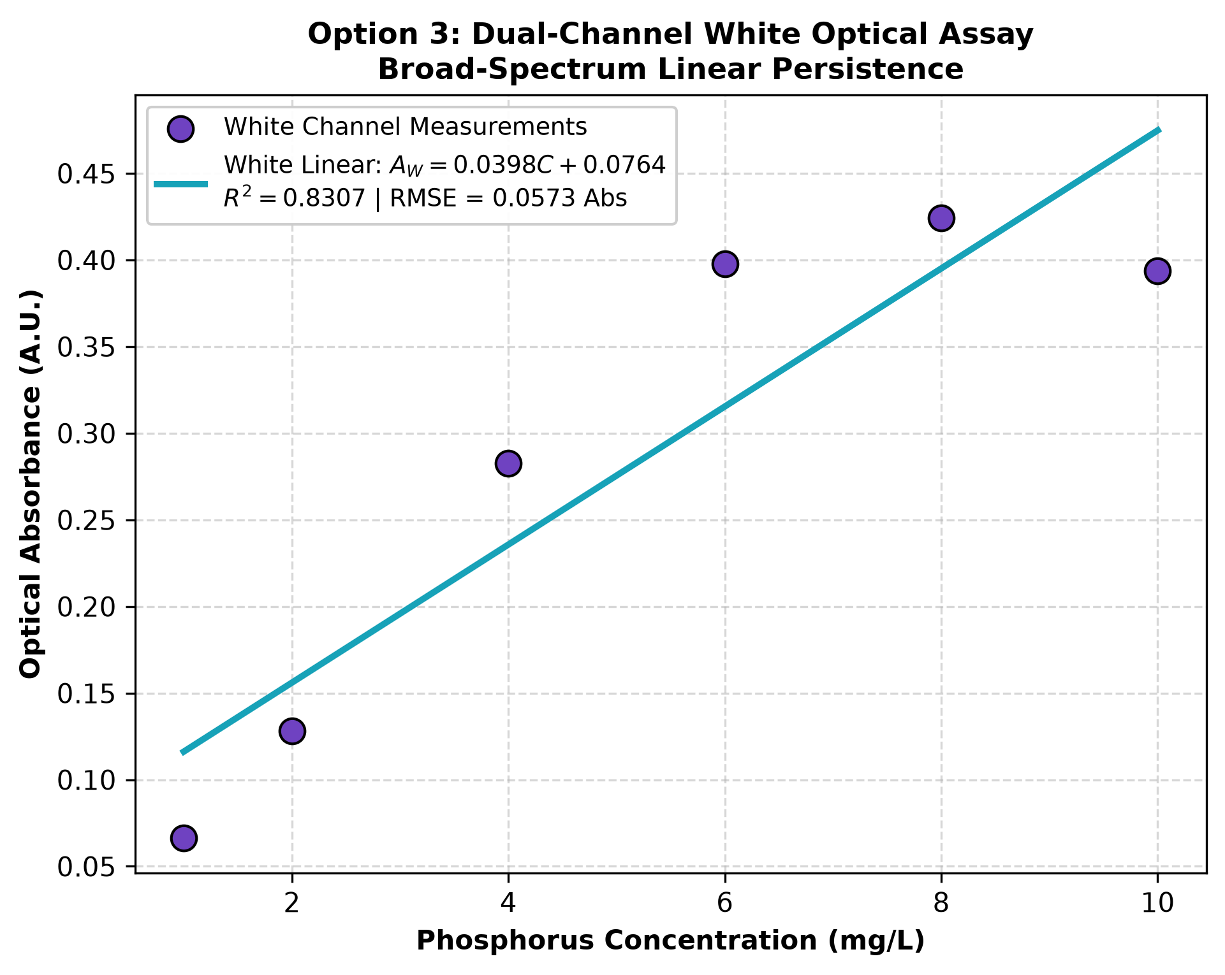
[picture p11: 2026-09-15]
research_q1_phosphorus/figures/option3_dual_channel_optics.png

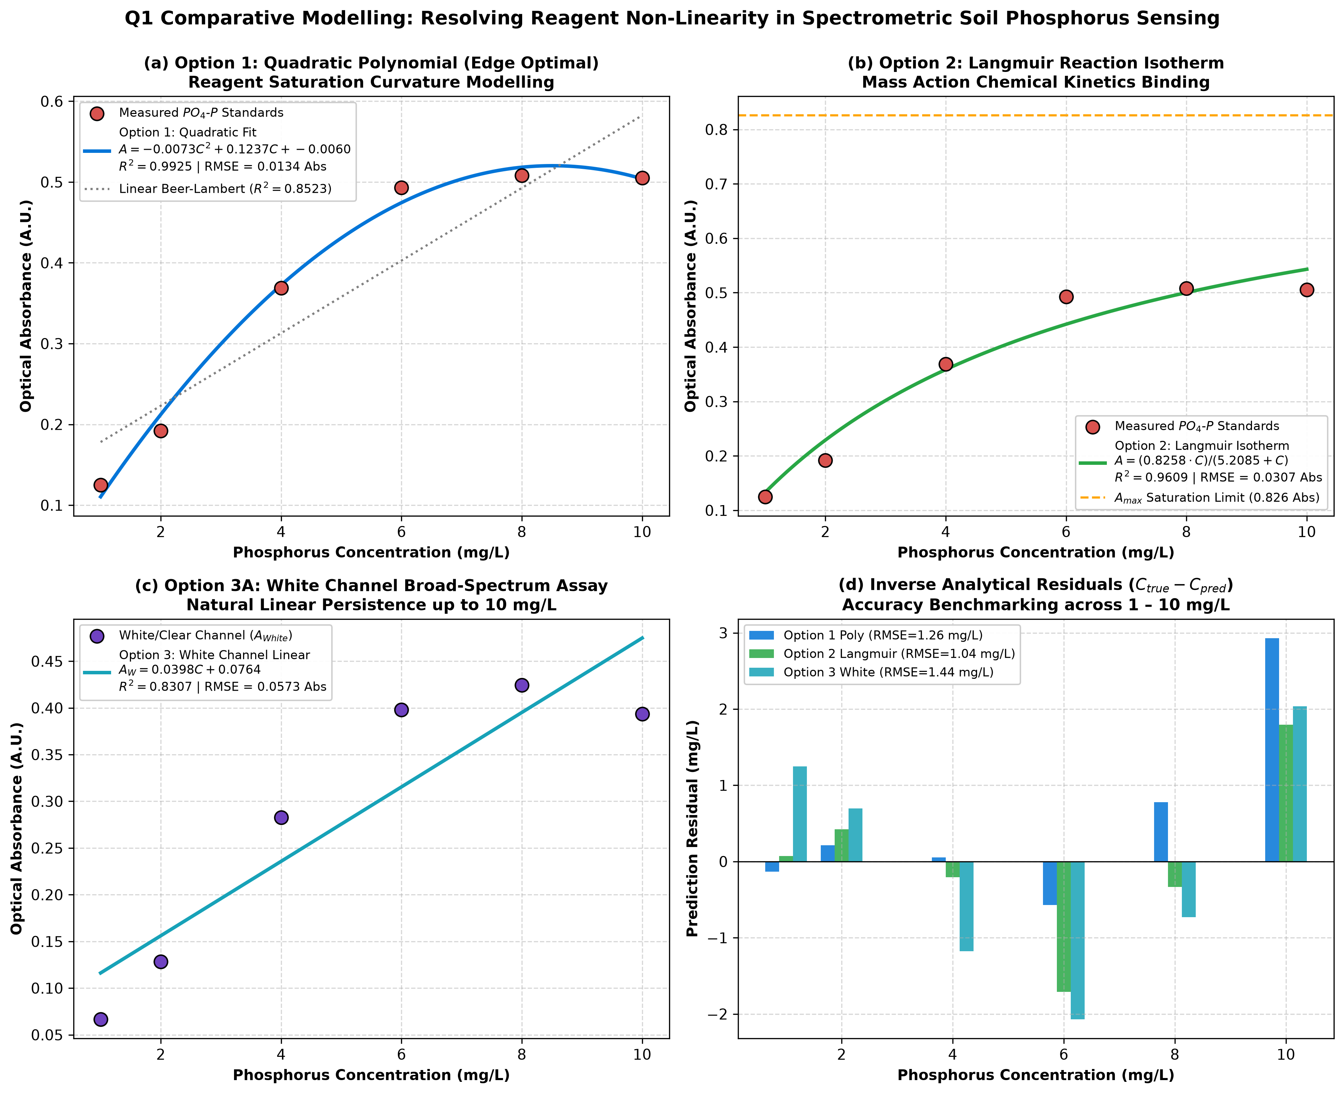
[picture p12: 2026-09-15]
research_papers/paper1_phosphorus_q1/figures/q1_comparative_modelling_phosphorus_1_10.png

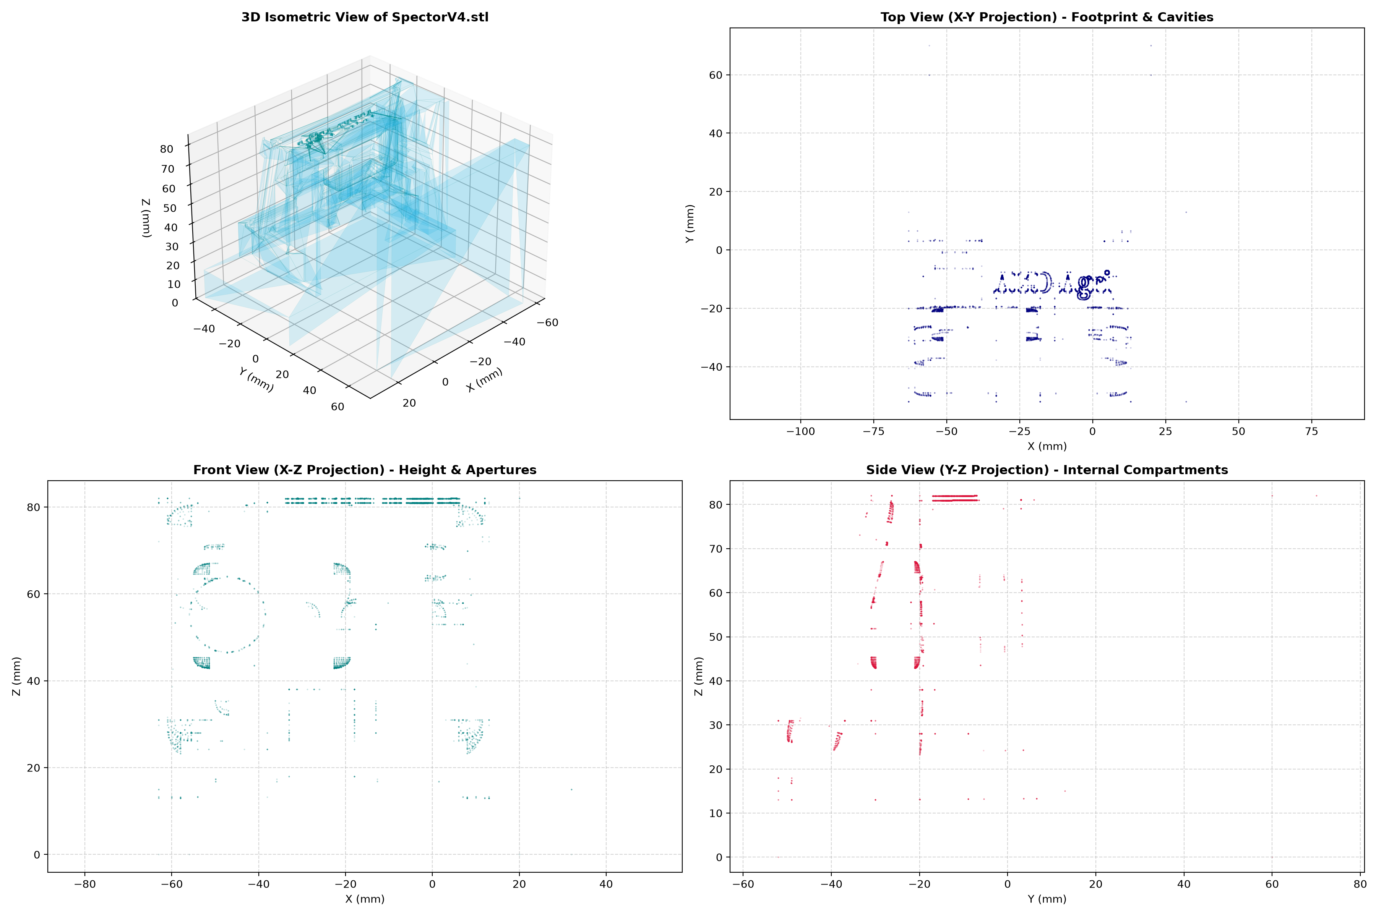
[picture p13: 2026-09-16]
models_3d/spectrometer/v4_chamber/spector_v4_analysis.png

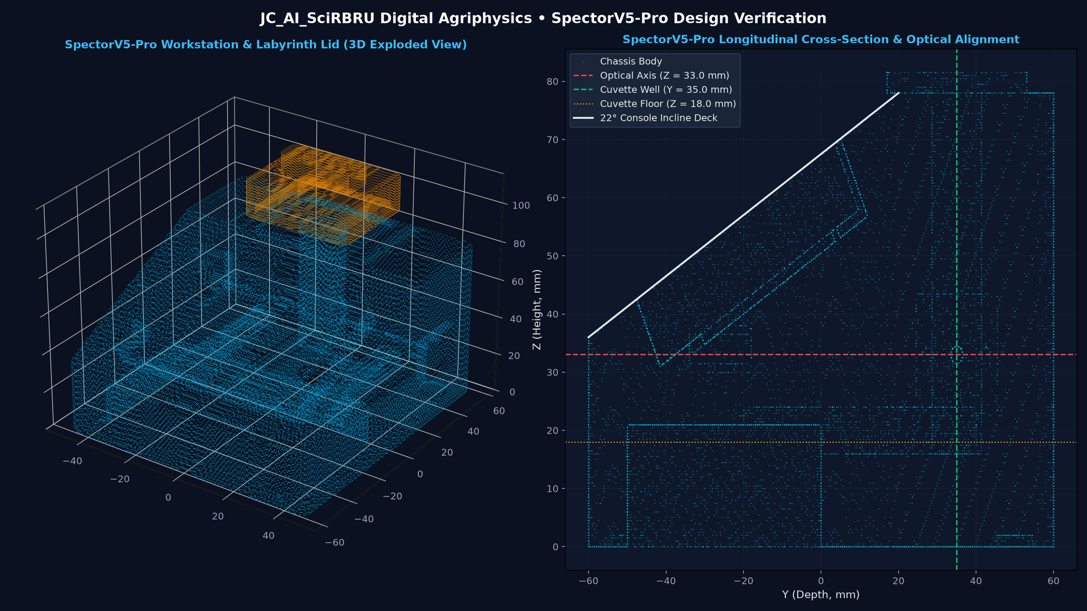
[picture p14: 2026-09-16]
models_3d/spectrometer/v5_workstation/spector_v5_analysis.png

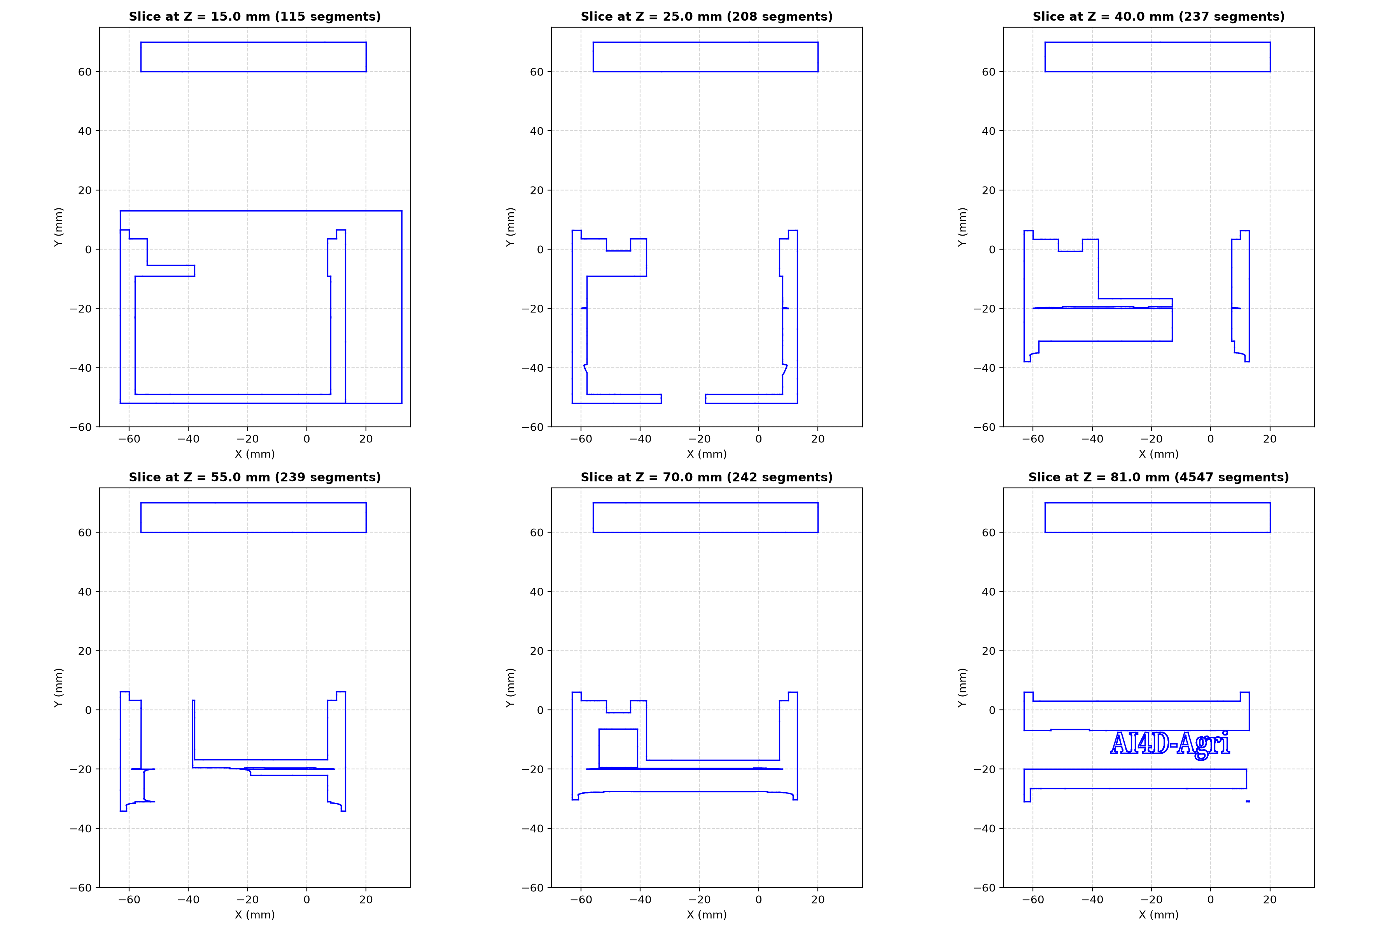
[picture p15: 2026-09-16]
models_3d/spectrometer/v4_chamber/spector_v4_slices.png

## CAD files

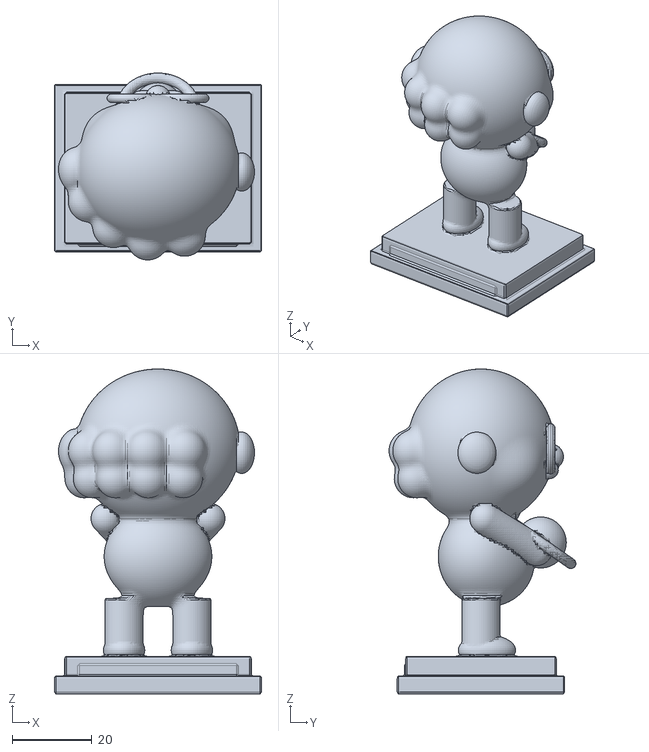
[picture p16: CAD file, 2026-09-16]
models_3d/quantum_physicists_chibi/planck_chibi_colored.ply
52.0 x 46.9 x 81.5

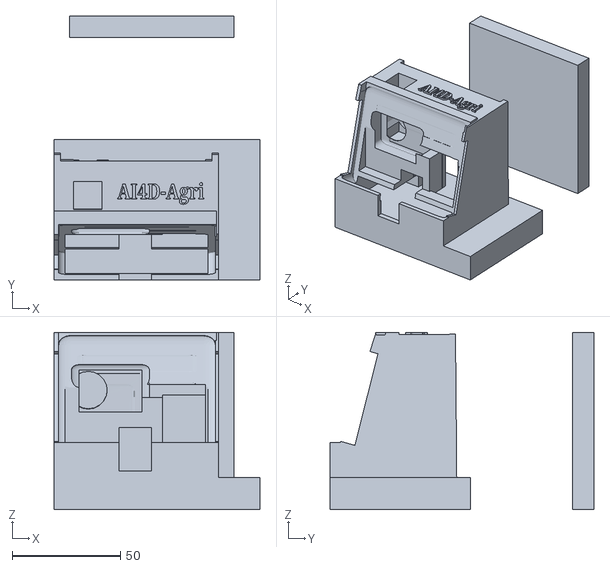
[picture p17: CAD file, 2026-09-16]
models_3d/spectrometer/v4_chamber/SpectorV4.stl
95.0 x 122.0 x 82.0

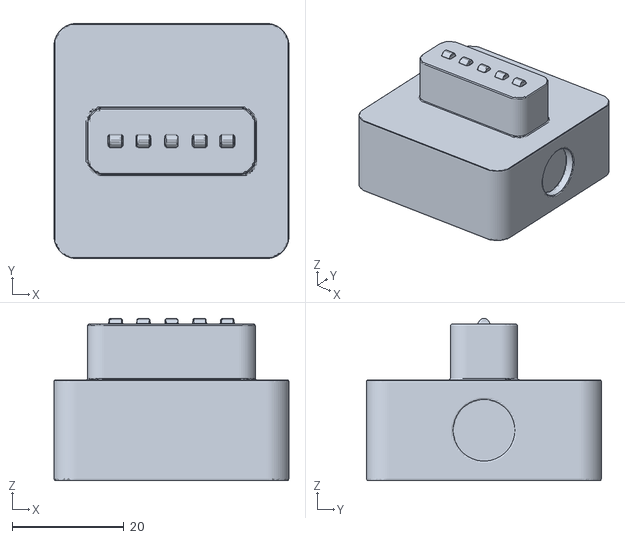
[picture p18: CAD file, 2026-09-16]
models_3d/spectrometer/v5_workstation/spector_v5_lid.stl
42.0 x 42.0 x 29.0

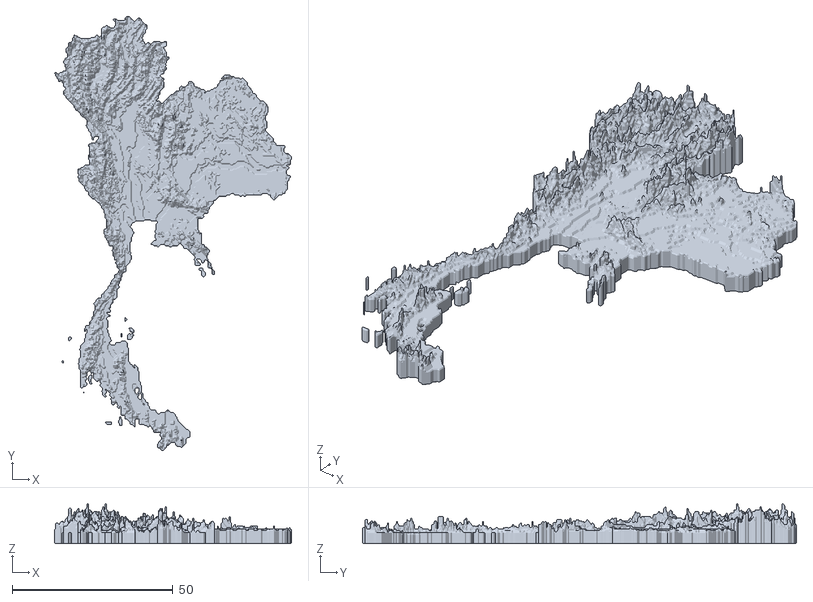
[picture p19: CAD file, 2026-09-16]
models_3d/thailand_map/thailand_country_standalone_3d.stl
73.7 x 134.9 x 12.5

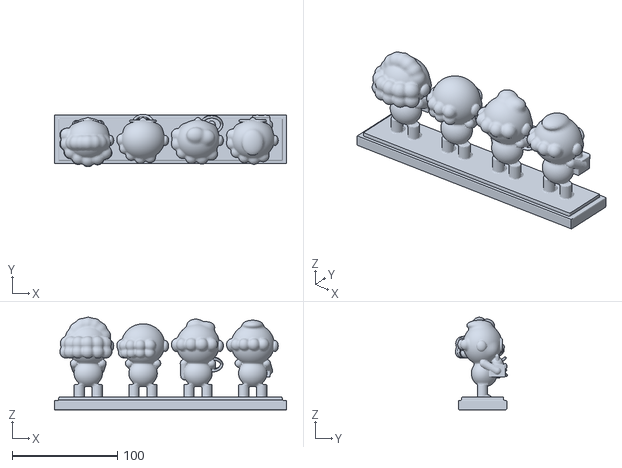
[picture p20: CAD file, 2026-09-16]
models_3d/quantum_physicists_chibi/quantum_quartet_diorama_colored.ply
220.0 x 49.8 x 87.8

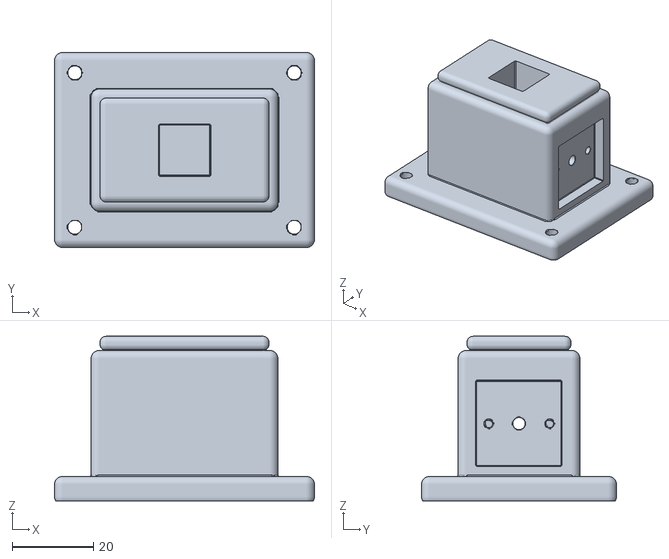
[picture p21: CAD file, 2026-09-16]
models_3d/spectrometer/v4_chamber/cuvette_optical_chamber.stl
64.0 x 48.0 x 40.5

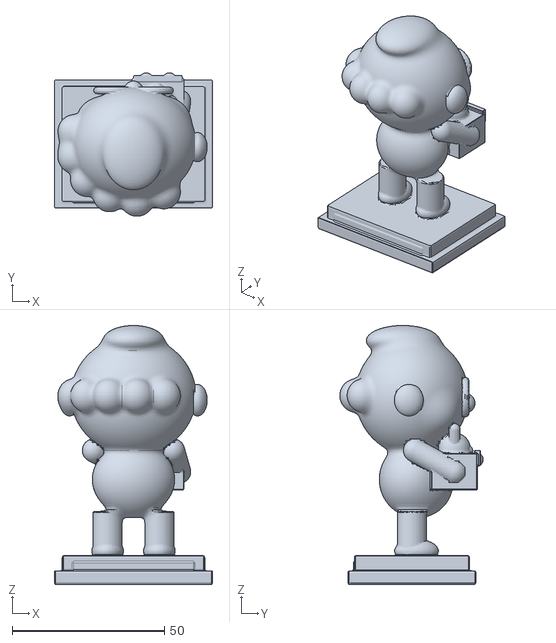
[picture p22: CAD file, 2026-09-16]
models_3d/quantum_physicists_chibi/schrodinger_chibi_colored.ply
52.0 x 47.1 x 85.0

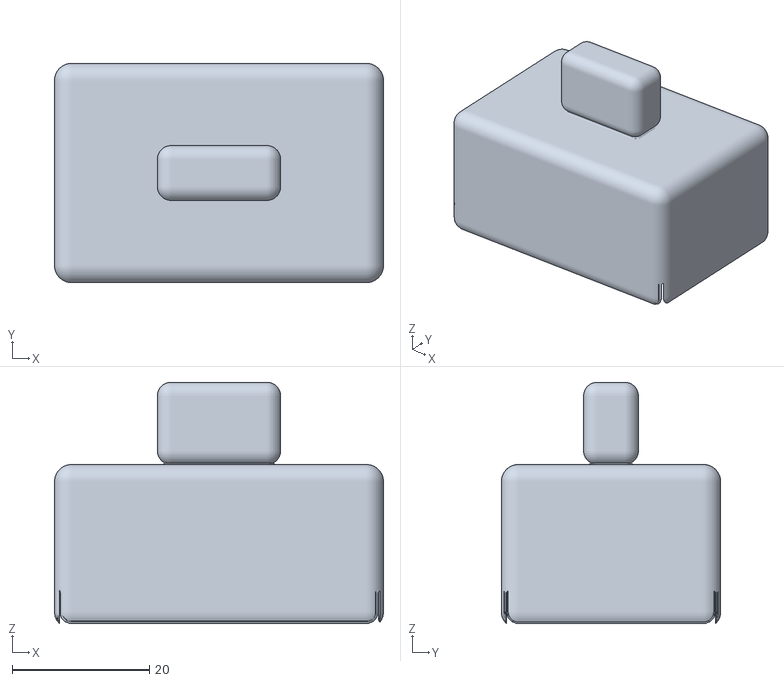
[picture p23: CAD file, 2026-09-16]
models_3d/spectrometer/v4_chamber/light_tight_lid.stl
48.0 x 32.0 x 35.2

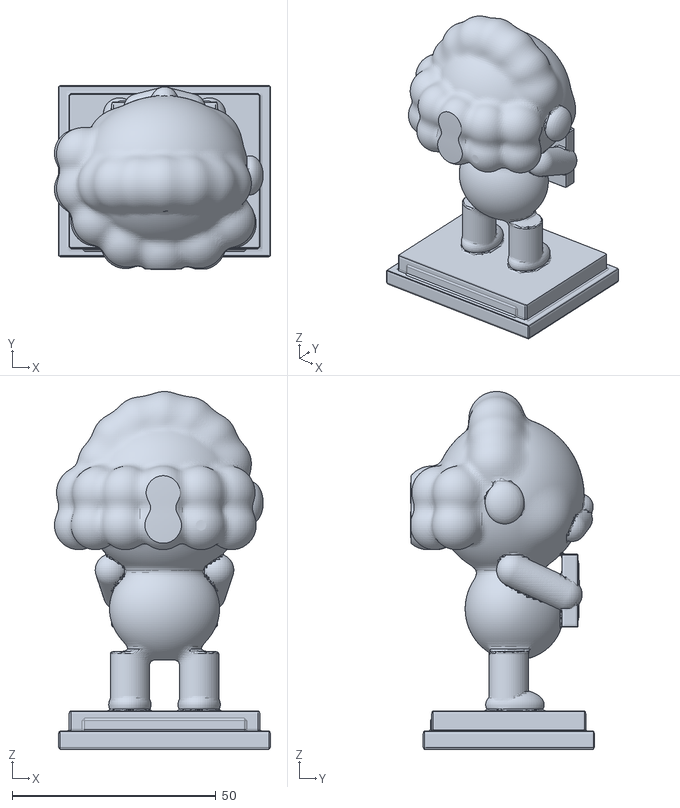
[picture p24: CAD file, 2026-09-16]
models_3d/quantum_physicists_chibi/einstein_chibi_colored.ply
53.0 x 45.1 x 87.8

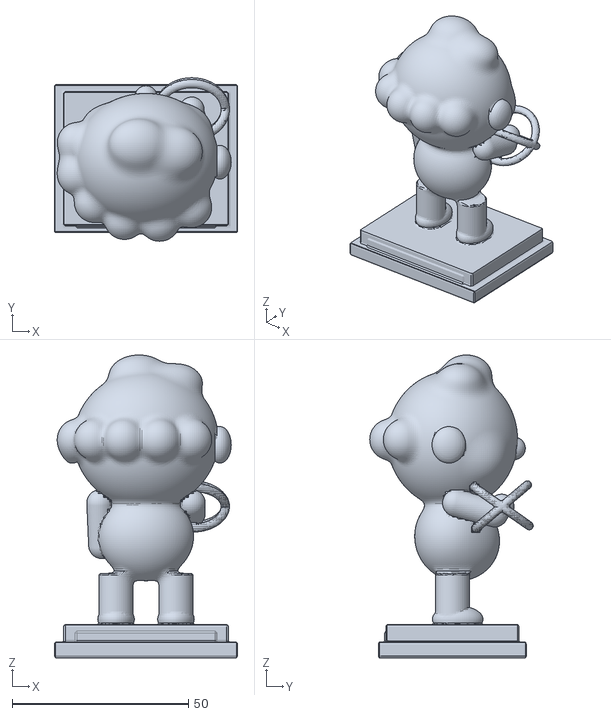
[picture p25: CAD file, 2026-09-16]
models_3d/quantum_physicists_chibi/heisenberg_chibi_colored.ply
52.0 x 46.4 x 86.0

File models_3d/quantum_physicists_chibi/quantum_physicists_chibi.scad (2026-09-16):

// ==============================================================================
// 🎨 QUANTUM PHYSICISTS CHIBI FIGURINE COLLECTION (PIXAR / GHIBLI STYLE)
// 🔬 Albert Einstein • Max Planck • Werner Heisenberg • Erwin Schrödinger
// 🏛️ หน่วยวิจัยฟิสิกส์เกษตรดิจิทัลและปัญญาประดิษฐ์ (AI4D AgriPhysics) มรภ.รำไพพรรณี
// ==============================================================================

$fn = 40; // Resolution for export (set to 24 for fast preview, 50 for final render)

// ------------------------------------------------------------------------------
// GLOBAL PARAMETERS (Chibi 1:2.5 Proportion)
// ------------------------------------------------------------------------------
total_height      = 100.0; // mm
plinth_width      = 55.0;  // mm
plinth_depth      = 45.0;  // mm
plinth_height     = 10.0;  // mm

head_radius_x     = 21.0;
head_radius_y     = 19.0;
head_radius_z     = 21.0;
head_center_z     = 62.0;

body_radius_x     = 14.0;
body_radius_y     = 12.0;
body_height       = 24.0;
body_center_z     = 36.0;

leg_radius        = 5.0;
leg_length        = 18.0;
leg_spread        = 8.5;

// ==============================================================================
// 1. BASE MODULES: PLINTH & CHIBI BODY RIG
// ==============================================================================

module chibi_plinth(name="Albert Einstein", formula="E = mc²") {
    difference() {
        union() {
            // Stepped wooden plinth base
            hull() {
                translate([-plinth_width/2, -plinth_depth/2, 0])
                    cylinder(r=3, h=4, $fn=16);
                translate([plinth_width/2, -plinth_depth/2, 0])
                    cylinder(r=3, h=4, $fn=16);
                translate([-plinth_width/2, plinth_depth/2, 0])
                    cylinder(r=3, h=4, $fn=16);
                translate([plinth_width/2, plinth_depth/2, 0])
                    cylinder(r=3, h=4, $fn=16);
            }
            translate([0, 0, 4])
                hull() {
                    translate([-plinth_width/2 + 3, -plinth_depth/2 + 3, 0])
                        cylinder(r=2, h=6, $fn=16);
                    translate([plinth_width/2 - 3, -plinth_depth/2 + 3, 0])
                        cylinder(r=2, h=6, $fn=16);
                    translate([-plinth_width/2 + 3, plinth_depth/2 - 3, 0])
                        cylinder(r=2, h=6, $fn=16);
                    translate([plinth_width/2 - 3, plinth_depth/2 - 3, 0])
                        cylinder(r=2, h=6, $fn=16);
                }
            // Brass nameplate plaque
            translate([0, -plinth_depth/2 + 1.5, 5])
                rotate([15, 0, 0])
                cube([plinth_width - 12, 2.5, 6], center=true);
        }
        // Bevel top edge slightly
    }
}

module chibi_lower_body() {
    // Left & Right Legs
    for (side = [-1, 1]) {
        translate([side * leg_spread, 0, 10]) {
            // Leg trousers
            cylinder(r1=leg_radius*1.1, r2=leg_radius*0.95, h=16);
            // Cute rounded shoe
            translate([0, 1.5, 0])
                scale([1.1, 1.4, 0.9])
                sphere(r=5.2);
        }
    }
}

module chibi_torso(jacket_type="sweater") {
    translate([0, 0, body_center_z]) {
        // Pear-shaped cute body
        scale([1, 0.88, 1])
            cylinder(r1=body_radius_x, r2=body_radius_x*0.75, h=body_height, center=true);
        
        // Belly softness
        translate([0, 2, -2])
            scale([1.05, 0.9, 0.95])
            sphere(r=body_radius_x*0.9);

        // Collar & tie / bowtie
        translate([0, 6, body_height/2 - 1]) {
            // Collar fold
            rotate([35, 0, 0])
                cube([10, 4, 3], center=true);
            if (jacket_type == "bowtie" || jacket_type == "suit") {
                // Cute Bowtie
                translate([0, 1.5, -2]) {
                    sphere(r=2);
                    translate([-3.2, 0, 0]) rotate([0, 20, 0]) cube([4, 2, 3], center=true);
                    translate([3.2, 0, 0]) rotate([0, -20, 0]) cube([4, 2, 3], center=true);
                }
            } else if (jacket_type == "tie") {
                // Necktie
                translate([0, 1.5, -5])
                    cube([3, 1.8, 8], center=true);
            }
        }
    }
}

module chibi_head_base() {
    // Oversized Pixar/Ghibli Head
    translate([0, 0, head_center_z]) {
        scale([head_radius_x, head_radius_y, head_radius_z] / 20)
            sphere(r=20);
        // Chubby cheeks
        translate([-11, 8, -4]) sphere(r=7.5);
        translate([11, 8, -4])  sphere(r=7.5);
        // Cute button nose
        translate([0, 18, -2])
            scale([1, 0.8, 0.8])
            sphere(r=3.2);
        // Cute ears
        translate([-head_radius_x - 1.5, 0, 0])
            rotate([0, 15, -10])
            scale([0.6, 0.9, 1.1])
            sphere(r=5.5);
        translate([head_radius_x + 1.5, 0, 0])
            rotate([0, -15, 10])
            scale([0.6, 0.9, 1.1])
            sphere(r=5.5);
    }
}

// Glasses Module
module chibi_round_spectacles(bridge_w=7, rim_r=6.5) {
    translate([0, 17.5, head_center_z]) {
        // Bridge
        translate([0, 0, 0])
            cube([bridge_w, 1.2, 1.5], center=true);
        // Left & Right wire rims
        for (side = [-1, 1]) {
            translate([side * (bridge_w/2 + rim_r - 0.5), 0, 0])
                rotate([90, 0, 0])
                difference() {
                    cylinder(r=rim_r, h=2, center=true);
                    cylinder(r=rim_r - 1.2, h=2.5, center=true);
                }
        }
    }
}

// ==============================================================================
// 2. CHARACTER MODULES (THE QUANTUM QUARTET)
// ==============================================================================

// ------------------------------------------------------------------------------
// A. ALBERT EINSTEIN (Wild Hair, Mustache, E=mc² Chalkboard)
// ------------------------------------------------------------------------------
module albert_einstein_chibi() {
    union() {
        chibi_plinth(name="Albert Einstein", formula="E = mc²");
        chibi_lower_body();
        chibi_torso(jacket_type="sweater");
        chibi_head_base();

        // 1. Wild fluffy curly hair (Multiple overlapping tufts)
        translate([0, 0, head_center_z]) {
            // Crown tufts
            for (ang = [-70:25:70]) {
                rotate([0, ang, 0])
                translate([0, -2, head_radius_z + 2])
                    sphere(r=6.5);
            }
            // Back & side curls
            for (a = [60:40:300]) {
                rotate([0, 0, a])
                translate([head_radius_x + 1, 0, 2])
                    scale([1.1, 1.1, 0.9])
                    sphere(r=7.0);
            }
            for (a = [90:50:270]) {
                rotate([0, 0, a])
                translate([head_radius_x + 3, 0, -6])
                    sphere(r=6.0);
            }
        }

        // 2. Iconic bushy mustache
        translate([0, 17.8, head_center_z - 6]) {
            scale([1.2, 0.9, 0.8]) {
                translate([-4.5, 0, -0.5]) rotate([0, 15, -10]) sphere(r=3.8);
                translate([4.5, 0, -0.5])  rotate([0, -15, 10]) sphere(r=3.8);
                sphere(r=3.0);
            }
        }

        // 3. Both Arms holding E = mc² Slate
        // Slate / Chalkboard
        translate([0, 15, body_center_z + 2]) {
            rotate([-12, 0, 0]) {
                // Wooden Frame
                cube([26, 3.5, 18], center=true);
                // Inner slate recessed
                translate([0, 0.5, 0])
                    cube([22, 3.0, 14], center=true);
            }
        }
        // Left & Right Arm
        for (side = [-1, 1]) {
            hull() {
                translate([side * 14, 2, body_center_z + 9]) sphere(r=4.5);
                translate([side * 11, 13, body_center_z + 1]) sphere(r=3.8);
            }
        }
    }
}

// ------------------------------------------------------------------------------
// B. MAX PLANCK (Distinguished Pince-Nez, Dark Suit & Glowing Quantum Orb)
// ------------------------------------------------------------------------------
module max_planck_chibi() {
    union() {
        chibi_plinth(name="Max Planck", formula="E = hν");
        chibi_lower_body();
        chibi_torso(jacket_type="bowtie");
        chibi_head_base();

        // 1. Neat distinguished parted hair & high bald forehead
        translate([0, 0, head_center_z]) {
            // Side & back hair fringe
            for (a = [80:30:280]) {
                rotate([0, 0, a])
                translate([head_radius_x - 1, 0, -2])
                    sphere(r=5.5);
            }
            // Parted hairline fringe
            translate([-head_radius_x/2, 10, head_radius_z - 4]) sphere(r=4);
            translate([head_radius_x/2, 10, head_radius_z - 4]) sphere(r=4);
        }
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

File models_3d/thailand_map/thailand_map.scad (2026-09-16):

// ==============================================================================
// Kingdom of Thailand - 3D Topographic Model
// Digital Agriphysics & AI Research Unit (JC_AI_SciRBRU)
// Department of Physics, Faculty of Science and Technology,
// Rambhai Barni Rajabhat University (RBRU)
// ==============================================================================

// --- User Parameters ---
model_scale_x       = 1.0;   // Scaling factor X
model_scale_y       = 1.0;   // Scaling factor Y
relief_multiplier   = 1.0;   // Vertical terrain exaggeration (1.0x - 3.0x)
base_pedestal_h     = 2.0;   // Additional base thickness (mm)

// Mode Selection: "plinth" or "standalone"
mode = "plinth"; 

module thailand_display_plinth() {
    scale([model_scale_x, model_scale_y, relief_multiplier])
        import("thailand_topographic_map_3d.stl");
}

module thailand_standalone_country() {
    scale([model_scale_x, model_scale_y, relief_multiplier])
        import("thailand_country_standalone_3d.stl");
}

if (mode == "plinth") {
    thailand_display_plinth();
} else if (mode == "standalone") {
    thailand_standalone_country();
}

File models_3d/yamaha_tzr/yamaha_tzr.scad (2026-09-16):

// ==============================================================================
// Yamaha TZR Series - Parametric 3D CAD Architecture
// Designed with Skill: motorcycle-3d-cad-architect
// Digital Agriphysics & AI Research Unit (JC_AI_SciRBRU)
// Department of Physics, Faculty of Science and Technology,
// Rambhai Barni Rajabhat University (RBRU)
//
// Key Features:
// 1. Yamaha Deltabox Aluminum Twin-Spar Frame
// 2. 2-Stroke Liquid-Cooled Engine with YPVS (Yamaha Power Valve System)
// 3. Tuned Racing Expansion Chamber Exhaust (Diffuser, Belly, Baffle & Silencer)
// 4. Aerodynamic 90s Racing Fairing with NACA Ducts & Bubble Windscreen
// 5. 17-inch 3-Spoke Sport Alloy Wheels with Disc Rotors
// 6. Monocross / Monoshock Rear Suspension & Box-Section Swingarm
// ==============================================================================

$fn = 36; // Curve smoothness

// --- User Parameters ---
scale_factor        = 1.0;   // Scale factor (1.0 = 1:10 scale, L ~ 200mm)
show_fairing        = true;  // Toggle outer racing fairings
show_paddock_stand  = true;  // Toggle racing paddock display stand
show_cutaway        = false; // Cross-section cutaway mode

// Color Palette (Classic Yamaha Racing Livery)
color_fairing_white = [0.95, 0.95, 0.95, 1.0];
color_fairing_red   = [0.85, 0.12, 0.12, 1.0];
color_windscreen    = [0.20, 0.60, 0.90, 0.45];
color_deltabox      = [0.78, 0.80, 0.82, 1.0]; // Polished Aluminum
color_engine        = [0.28, 0.28, 0.30, 1.0]; // Dark Graphite Case
color_exhaust       = [0.18, 0.18, 0.20, 1.0]; // Heat-treated Steel
color_silencer      = [0.85, 0.85, 0.88, 1.0]; // Brushed Aluminum
color_tire          = [0.12, 0.12, 0.14, 1.0]; // Rubber
color_rim           = [0.95, 0.95, 0.95, 1.0]; // White Racing Wheels
color_seat          = [0.15, 0.15, 0.15, 1.0]; // Black Vinyl
color_stand         = [0.85, 0.15, 0.15, 1.0]; // Red Paddock Stand

// Dimensions (1:10 Scale in mm)
wheelbase           = 135.0; // Front axle at +67.5, Rear axle at -67.5
wheel_radius        = 30.0;  // 17" Wheel equivalent

// --- Module: Wheels & Brakes ---
module tzr_wheel(x_pos, is_rear=false) {
    width_tire = is_rear ? 15.0 : 11.0;
    r_tire     = is_rear ? 6.5 : 5.5;
    r_major    = 30.0 - r_tire;
    
    translate([x_pos, 0, 30.0]) {
        // Rubber Tire (Torus)
        color(color_tire)
            rotate([90, 0, 0])
                rotate_extrude()
                    translate([r_major, 0, 0])
                        circle(r=r_tire);
                        
        // Alloy Rim (Ring)
        color(color_rim) {
            rotate([90, 0, 0])
                difference() {
                    cylinder(r=21.0, h=width_tire - 2, center=true);
                    cylinder(r=18.0, h=width_tire, center=true);
                }
            // Center Hub
            rotate([90, 0, 0])
                cylinder(r=6.5, h=width_tire + 2, center=true);
                
            // 3-Spoke Sport Design
            for (ang = [0, 120, 240]) {
                rotate([0, ang, 0])
                    translate([0, 0, 10.0])
                        cube([4.0, 3.5, 18.0], center=true);
            }
        }
        
        // Brake Rotors
        color([0.7, 0.7, 0.75, 1.0]) {
            if (!is_rear) {
                // Front Twin Discs
                for (s = [-1, 1]) {
                    translate([0, s * 6.5, 0])
                        rotate([90, 0, 0])
                            cylinder(r=15.5, h=1.2, center=true);
                    // Caliper
                    translate([-10.0, s * 7.5, 3.0])
                        cube([8.0, 3.5, 10.0], center=true);
                }
            } else {
                // Rear Single Disc (Right side)
                translate([0, -6.5, 0])
                    rotate([90, 0, 0])
                        cylinder(r=13.0, h=1.2, center=true);
                // Chain Sprocket (Left side)
                translate([0, 7.0, 0])
                    rotate([90, 0, 0])
                        cylinder(r=14.5, h=1.5, center=true);
            }
        }
    }
}

// --- Module: Front Fork & Triple Clamps ---
module tzr_front_fork() {
    translate([0, 0, 0]) {
        // Telescopic Fork Legs
        color(color_deltabox) {
            for (s = [-1, 1]) {
                // Stanchion (Chrome Upper)
                hull() {
                    translate([38.0, s * 11.5, 74.0]) sphere(r=3.2);
                    translate([52.0, s * 11.5, 52.0]) sphere(r=3.2);
                }
                // Slider (Lower Cast)
                hull() {
                    translate([52.0, s * 11.5, 52.0]) sphere(r=4.5);
                    translate([67.5, s * 11.5, 30.0]) sphere(r=4.5);
                }
            }
            // Triple Clamps
            translate([38.0, 0, 74.0]) cube([8.0, 27.0, 4.0], center=true);
            translate([42.0, 0, 65.0]) cube([9.0, 27.0, 5.0], center=true);
        }
        
        // Clip-on Handlebars
        color([0.2, 0.2, 0.22, 1.0]) {
            for (s = [-1, 1]) {
                hull() {
                    translate([38.0, s * 11.5, 74.0]) sphere(r=2.5);
                    translate([30.0, s * 31.0, 69.0]) sphere(r=2.5);
                }
                // Grips
                hull() {
                    translate([33.0, s * 23.0, 70.5]) sphere(r=3.2);
                    translate([30.0, s * 31.0, 69.0]) sphere(r=3.2);
                }
            }
        }
        
        // Cockpit Instrument Cluster
        color([0.15, 0.15, 0.15, 1.0]) {
            translate([43.0,  6.0, 77.0]) cylinder(r=5.5, h=4.0, center=true);
            translate([43.0, -6.0, 77.0]) cylinder(r=5.5, h=4.0, center=true);
        }
    }
}

// --- Module: Deltabox Aluminum Frame ---
module tzr_deltabox_frame() {
    color(color_deltabox) {
        // Steering Head
        translate([38.0, 0, 70.0])
            cylinder(r=7.0, h=16.0, center=true);
            
        // Left & Right Twin-Spar Beams
        for (s = [-1, 1]) {
            // Forward Beam
            hull() {
                translate([36.0, s * 11.0, 70.0]) sphere(r=6.5);
                translate([15.0, s * 16.0, 60.0]) sphere(r=7.5);
            }
            // Rear Diagonal Beam to Swingarm Pivot
            hull() {
                translate([15.0, s * 16.0, 60.0]) sphere(r=7.5);
                translate([-25.0, s * 18.0, 38.0]) sphere(r=8.5);
            }
            // Down-tubes / Engine Cradle
            hull() {
                translate([34.0, s * 9.0, 64.0]) sphere(r=3.2);
                translate([-2.0, s * 12.0, 26.0]) sphere(r=3.2);
            }
            hull() {
                translate([-2.0, s * 12.0, 26.0]) sphere(r=3.2);
                translate([-22.0, s * 14.0, 27.0]) sphere(r=3.5);
            }
            // Rear Subframe Tubes
            hull() {
                translate([-25.0, s * 16.0, 44.0]) sphere(r=3.0);
                translate([-78.0, s * 9.0, 66.0]) sphere(r=3.0);
            }
            hull() {
                translate([-25.0, s * 16.0, 38.0]) sphere(r=2.8);
                translate([-55.0, s * 11.0, 58.0]) sphere(r=2.8);
            }
            // Footpegs
            translate([-24.0, s * 22.0, 33.0])
                rotate([90, 0, 0]) cylinder(r=2.5, h=10.0, center=true);
        }
        
        // Frame Cross-Brace
        translate([12.0, 0, 63.0])
            cube([10.0, 26.0, 7.0], center=true);
    }
}

// --- Module: 2-Stroke YPVS Engine & Radiator ---
module tzr_engine() {
    // Crankcase
    color(color_engine) {
        translate([-7.0, 0, 33.0])
            cube([28.0, 24.0, 20.0], center=true);
            
        // Right Clutch Casing
        translate([-7.0, -13.0, 33.0])
            rotate([90, 0, 0])
                cylinder(r=10.5, h=5.0, center=true);
                
        // Left Magneto Cover
        translate([-7.0, 13.0, 33.0])
            rotate([90, 0, 0])
                cylinder(r=9.5, h=4.5, center=true);
                
        // Slanted Cylinder Block (45 degrees forward)
        hull() {
            translate([-2.0, 0, 40.0]) sphere(r=9.5);
            translate([13.0, 0, 55.0]) sphere(r=9.0);
        }
        // Cylinder Head & Fins
        translate([15.0, 0, 57.0])
            sphere(r=8.5);
            
        // YPVS Chamber (Yamaha Power Valve System)
        translate([13.0, 0, 51.0])
            rotate([90, 0, 0])
                cylinder(r=4.2, h=18.0, center=true);
    }
    
    // Curved Radiator (Behind front wheel)
    color([0.35, 0.38, 0.40, 1.0]) {
        translate([27.0, 0, 45.0])
            cube([5.0, 32.0, 18.0], center=true);
    }
}
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

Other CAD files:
models_3d/quantum_physicists_chibi/schrodinger_chibi_3d.stl
models_3d/quantum_physicists_chibi/einstein_chibi_3d.stl
models_3d/quantum_physicists_chibi/heisenberg_chibi_3d.stl
models_3d/quantum_physicists_chibi/planck_chibi_3d.stl
models_3d/quantum_physicists_chibi/quantum_quartet_diorama_3d.stl
models_3d/spectrometer/v4_chamber/cuvette_optical_chamber.scad
models_3d/spectrometer/v4_chamber/light_tight_lid.scad
models_3d/spectrometer/v4_chamber/spectrometer_assembly.scad
models_3d/spectrometer/v5_workstation/spector_v5_lid.scad
models_3d/spectrometer/v5_workstation/spector_v5_workstation.scad

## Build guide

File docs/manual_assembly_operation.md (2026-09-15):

# คู่มือการประกอบ ติดตั้ง และใช้งานเครื่องสเปกโทรโฟโตมิเตอร์ตรวจวัดธาตุอาหารหลักในดินและสมบัติเชิงแสงของของเหลว
## (NPK Level Meter 1.02 & Liquid Optics Metrology Analyzer)

**หน่วยวิจัยเกษตรดิจิทัล JC_AI_SciRBRU (Digital Agriphysics & AI Research Unit)**  
**สาขาวิชาฟิสิกส์ คณะวิทยาศาสตร์และเทคโนโลยี มหาวิทยาลัยราชภัฏรำไพพรรณี**

---

## สารบัญ
1. บทนำและหลักการฟิสิกส์เชิงแสง
2. การออกแบบและประกอบชิ้นส่วนฮาร์ดแวร์
3. การติดตั้งเฟิร์มแวร์และการตั้งค่าซอฟต์แวร์
4. สถาปัตยกรรม 8 หน้าจอและการควบคุมการทำงาน (8-Screen Carousel UI)
5. ทฤษฎีและแบบจำลองการคำนวณเคมีวิเคราะห์
6. ขั้นตอนการปฏิบัติการตรวจวัดธาตุอาหารในดิน (NPK Soil Testing)
7. ขั้นตอนการปฏิบัติการตรวจวัดสมบัติของเหลว (Liquid Optics Metrology)
8. การเทียบมาตรฐานและการสร้างเส้นโค้งมาตรฐาน (In-Situ Standard Curve Wizard)
9. โครงสร้างการบันทึกข้อมูลบนการ์ดหน่วยความจำ microSD Card
10. การบำรุงรักษาและการแก้ไขปัญหาเบื้องต้น
11. การเชื่อมต่อเครือข่าย Wi-Fi และสถาปัตยกรรม JSON REST Server
12. ระบบเว็บแอปพลิเคชันแดชบอร์ดและฐานข้อมูล JSON (Web Dashboard)

---

## 1. บทนำและหลักการฟิสิกส์เชิงแสง

การตรวจวัดปริมาณธาตุอาหารหลักในดิน (ไนโตรเจน N, ฟอสฟอรัส P, และโพแทสเซียม K) รวมถึงการประเมินสมบัติเชิงแสงและกายภาพของของเหลวทางการเกษตร (เช่น น้ำหมักชีวภาพ น้ำชลประทาน สารละลายธาตุอาหารพืช) มีความจำเป็นอย่างยิ่งต่อการทำเกษตรแม่นยำ (Precision Agriculture)

ระบบสเปกโทรโฟโตมิเตอร์ NPK Level Meter 1.02 อาศัยหลักการทางทัศนศาสตร์ฟิสิกส์ตาม **กฎของเบียร์และแลมเบิร์ต (Beer-Lambert Law)**

$$A(\lambda) = -\log_{10}\left(\frac{I(\lambda) - I_{	ext{dark}}}{I_0(\lambda) - I_{	ext{dark}}}
ight) = \varepsilon(\lambda) \cdot b \cdot C$$

โดยที่
- $A(\lambda)$ คือ ค่าการดูดกลืนแสง (Absorbance) ณ ความยาวคลื่น $\lambda$
- $I_0(\lambda)$ คือ ความเข้มแสงเริ่มต้นที่ส่องผ่านสารละลายแบลงก์ (Blank Reference)
- $I(\lambda)$ คือ ความเข้มแสงที่ทะลุผ่านสารละลายตัวอย่าง (Sample Intensity)
- $I_{	ext{dark}}$ คือ สัญญาณกระแสมืดของเซนเซอร์ขณะดับไฟ (Dark Current)
- $b$ คือ ความยาวทางเดินแสงในคิวเวตต์ ($1.0	ext{ cm}$)
- $C$ คือ ความเข้มข้นของสารละลาย ($	ext{mg/kg}$)

### การเลือกความยาวคลื่นในการวิเคราะห์
1. **แสงสีน้ำเงิน ($\lambda \approx 465	ext{ nm}$):** ตรวจวัด ไนโตรเจน (N) สารละลายสีส้มอมน้ำตาล
2. **แสงสีฟ้าอมเขียว ($\lambda \approx 500	ext{ nm}$):** ตรวจวัดสารสีอินทรีย์และการดูดกลืนแสงช่วงสเปกตรัมกลาง
3. **แสงสีเขียว ($\lambda \approx 525	ext{ nm}$):** ตรวจวัด ฟอสฟอรัส (P) สารประกอบเชิงซ้อนสีน้ำเงินโมลิบดีนัม
4. **แสงสีเหลือง ($\lambda \approx 590	ext{ nm}$):** ตรวจวัดอนุภาคแขวนลอยและค่าความขุ่น
5. **แสงสีแดง ($\lambda \approx 625	ext{ nm}$):** ตรวจวัด โพแทสเซียม (K) ตะกอนแขวนลอยเตตระฟีนิลบอเรต

---

## 2. การออกแบบและประกอบชิ้นส่วนฮาร์ดแวร์

### 2.1 รายการอุปกรณ์
1. **บอร์ดประมวลผล:** Seeed Studio Wio Terminal (ไมโครคอนโทรลเลอร์ Microchip ATSAMD51P19A, Cortex-M4F 120 MHz, FPU, จอ LCD 2.4 นิ้ว)
2. **เซนเซอร์วัดค่าสีดิจิทัล:** Adafruit TCS34725 (โฟโตไดโอด RGBC พร้อมฟิลเตอร์ตัดแสงอินฟราเรด)
3. **แหล่งกำเนิดแสงหลายช่วงคลื่น:** Grove RGB LED (หลอดดิจิทัล WS2812B ให้ความยาวคลื่นเสถียร)
4. **แท่นยึดคิวเวตต์ (Cuvette Holder):** รองรับหลอดทดลองมาตรฐานทางเดินแสง $10	ext{ mm}$
5. **การ์ดหน่วยความจำ:** microSD Card Class 10 ฟอร์แมต FAT32

### 2.2 ตารางการเชื่อมต่อขาสัญญาณ
| อุปกรณ์ภายนอก | พอร์ตบน Wio Terminal | ขาสัญญาณไมโคร | หน้าที่ |
| :--- | :--- | :--- | :--- |
| TCS34725 (SDA) | Grove พอร์ตขวา | PA17 | สายส่งข้อมูล I2C (100 kHz) |
| TCS34725 (SCL) | Grove พอร์ตขวา | PA16 | สายสัญญาณนาฬิกา I2C (100 kHz) |
| TCS34725 (VCC) | Grove พอร์ตขวา | 3V3 | แรงดันไฟฟ้ากระแสตรง 3.3 โวลต์ |
| TCS34725 (GND) | Grove พอร์ตขวา | GND | กราวด์ร่วมของระบบ |
| RGB LED (DIN) | Grove พอร์ตซ้าย | PB08 (D0) | สายข้อมูลควบคุมหลอด NeoPixel |
| RGB LED (VCC) | Grove พอร์ตซ้าย | 5V | แรงดันไฟฟ้าเลี้ยงหลอดไฟ 5 โวลต์ |
| RGB LED (GND) | Grove พอร์ตซ้าย | GND | กราวด์ร่วมของหลอดไฟ |

---

## 3. การติดตั้งเฟิร์มแวร์และการตั้งค่าซอฟต์แวร์

### 3.1 ไลบรารีที่จำเป็น
- `Seeed_Arduino_LCD` (เวอร์ชันสำหรับ Wio Terminal โดยเฉพาะ ห้ามติดตั้งทับด้วย TFT_eSPI ทั่วไป)
- `Adafruit_TCS34725`
- `Adafruit_NeoPixel`
- `Seeed_Arduino_FS` และ `Seeed_SD`

> **ข้อกำหนดสำคัญ:** ในไฟล์ `User_Setup.h` ของ `Seeed_Arduino_LCD` ต้องเปิด `#define SMOOTH_FONT` เพื่อให้แสดงผลฟอนต์ภาษาไทย THSarabunPSK บนจอ LCD ได้อย่างคมชัด

### 3.2 คำสั่งคอมไพล์และอัปโหลด
```bash
# คอมไพล์โปรแกรม
arduino-cli compile --fqbn Seeeduino:samd:seeed_wio_terminal firmware/spectrometer_npk2026

# แฟลชโปรแกรมเข้าสู่บอร์ด Wio Terminal
arduino-cli upload -p /dev/cu.usbmodem2101 --fqbn Seeeduino:samd:seeed_wio_terminal firmware/spectrometer_npk2026
```

---

## 4. สถาปัตยกรรม 8 หน้าจอและการควบคุมการทำงาน (8-Screen Carousel UI)

ระบบแสดงผลบนจอ LCD ขนาด 2.4 นิ้ว (320x240 พิกเซล) แบ่งออกเป็น 8 หน้าจอแบบ Carousel หมุนวนอย่างราบรื่น:

| หน้าจอ | รหัสหน้า | วัตถุประสงค์หลักและการแสดงผลเด่น |
| :---: | :--- | :--- |
| **Page 1** | `[1/8]` System Dashboard | แดชบอร์ดระบบ: แสดงหัวข้อ "สเปกโทรโฟโตมิเตอร์" จัดกึ่งกลางจอขนาดใหญ่ขึ้น 10%, ตราสัญลักษณ์เวกเตอร์ปริซึมออปติก, แบรนด์ **`SpecJC +AI Analyzer`** จัดกึ่งกลางจอขนาดใหญ่ขึ้น 10% (Spec สีฟ้า `0x07FF`, JC สีแดง `TFT_RED`, +AI สีเหลือง `TFT_YELLOW`, Analyzer สีเขียว `TFT_GREEN`), โหมด **`AI TinyML`** (ลดขนาดและตัดวงเล็บ [ ] ออกเพื่อความกะทัดรัด), "เกษตรดิจิทัล", นาฬิกา RTC ปรับเทียบเวลาจริงอัตโนมัติ (ปรับตำแหน่งต่ำลงมาเพื่อไม่ให้ซ้อนทับ) และสถานะชิป/เซนเซอร์ |
| **Page 2** | `[2/8]` Dedicated Nitrogen Assay | วิเคราะห์ปริมาณไนโตรเจน (จัดกึ่งกลางจอ สีฟ้า Cyan `0x07FF`): สลับไฟ **Blue LED (465 nm)** อัตโนมัติ, แสดงผลตัวเลขขนาดใหญ่ พร้อมตัวอักษร **`N` ขนาดใหญ่พิเศษ (TextSize 4) ตัวหนา สีชมพูอมม่วง (Magenta)** ต่อท้ายหน่วย $\text{mg/kg}$, แถบสเกลวัดระดับยกสูงขึ้น ($y=126..134$) ป้องกันการซ้อนทับกับข้อความผลการวิเคราะห์ภาษาไทย |
| **Page 3** | `[3/8]` Dedicated Phosphorus Assay | วิเคราะห์ปริมาณฟอสฟอรัส (จัดกึ่งกลางจอ สีเขียว `TFT_GREEN`): สลับไฟ **Red LED (625 nm)** อัตโนมัติ, แสดงผลตัวเลขขนาดใหญ่ พร้อมตัวอักษร **`P` ขนาดใหญ่พิเศษ (TextSize 4) ตัวหนา สีฟ้าสด (Cyan)**, หน่วย $\text{mg/kg}$ ปรับเลื่อนออกไปที่ตำแหน่งพิกัด $x=172$ เพื่อความสวยงามลงตัวไม่เบียดชิด, แท็ก $A_{625}$ และแท็กสถานะที่ $x=172$, แถบสเกลยกสูงขึ้นป้องกันการซ้อนทับข้อความภาษาไทย |
| **Page 4** | `[4/8]` Dedicated Potassium Assay | วิเคราะห์ปริมาณโพแทสเซียม (จัดกึ่งกลางจอ สีแดง `TFT_RED`): สลับไฟ **Red LED (625 nm)** อัตโนมัติ, แสดงผลตัวเลขขนาดใหญ่ พร้อมตัวอักษร **`K` ขนาดใหญ่พิเศษ (TextSize 4) ตัวหนา สีแดงสด (Red)** ต่อท้ายหน่วย $\text{mg/kg}$, แถบสเกลยกสูงขึ้นป้องกันการบดบังข้อความภาษาไทย |
| **Page 5** | `[5/8]` Soil pH Assay | วิเคราะห์ความเป็นกรด ด่าง (จัดกึ่งกลางจอ สีเหลือง `TFT_YELLOW`): สลับไฟ **Dual Green/Red LED (525/625 nm)** อัตโนมัติ, แสดงข้อความ **`pH Level` ขนาดใหญ่ (TextSize 3) ตัวหนา Multi-Pass สีฟ้าสดและเหลืองนีออน**, แถบสเกล $3.5 - 8.5\text{ pH}$ ปรับระดับยกสูงขึ้นป้องกันการบดบังข้อความ และคำแนะนำปรับปรุงดินสำหรับสวนทุเรียน |
| **Page 6** | `[6/8]` Full NPK Nutrient Matrix | ตารางสรุปภาพรวมธาตุอาหารดิน 3 ชนิด (N, P, K) พร้อมแถบวัดระดับความอุดมสมบูรณ์ (ต่ำ-เหมาะสม-สูง) |
| **Page 7** | `[7/8]` In-Situ Calibration Wizard | ระบบเทียบมาตรฐานและสร้างเส้นโค้ง OLS ($R^2$, ความชัน $m$, จุดตัด $c$, LOD, LOQ ตามมาตรฐาน IUPAC/ISO 17025) |
| **Page 8** | `[8/8]` System Diagnostics & Core Info | การวินิจฉัยระบบ: สวิตช์สลับโหมดโมเดล AI TinyML / PL Poly / SC StdCurv, อุณหภูมิ, หน่วยความจำ และเครดิต ผศ.ดร.ชีวะ ทัศนา และ ผศ.ดร.จิรภัทร จันทมาลี (ปรับขนาดฟอนต์กะทัดรัดลงตัว ไม่บดบังข้อมูล) พร้อมแบรนด์ `SpecJC +AI Analyzer` |

### ระบบเปลี่ยนความยาวคลื่นแสงอัตโนมัติ (Auto-Wavelength Switching Engine)
เพื่อป้องกันข้อผิดพลาดในการเปิดแสงผิดสีของผู้ปฏิบัติงาน เฟิร์มแวร์จะเปลี่ยนแหล่งกำเนิดแสง LED ตามฟังก์ชันการตรวจวัดทันทีที่เปลี่ยนหน้าจอ:
- **หน้า 2 (Nitrogen):** เปิดไฟสีน้ำเงิน (465 nm) ดูดกลืนสูงสุดกับสารสกัดไนเตรต/แอมโมเนีย
- **หน้า 3 (Phosphorus):** เปิดไฟสีแดง (625 nm) ดูดกลืนสูงสุดกับสารเชิงซ้อนฟอสโฟโมลิบดีนัมบลู
- **หน้า 4 (Potassium):** เปิดไฟสีแดง (625 nm) วัดการลดทอนความเข้มแสงและการกระเจิงจากตะกอนเตตระฟีนิลบอเรต
- **หน้า 5 (Soil pH):** เปิดไฟคู่เขียว/แดง (525/625 nm) วิเคราะห์อัตราส่วนสีสีย้อมอินดิเคเตอร์

### การสั่งงานด้วยปุ่มกดและจอยสติ๊ก
- **จอยสติ๊กโยกซ้าย / ขวา (`WIO_5S_LEFT / RIGHT`):** เลื่อนสลับหน้าจอวนลูป 8 หน้าจอ
- **จอยสติ๊กโยกขึ้น (`WIO_5S_UP`):** หน้า Dashboard / NPK / System Info: สลับโหมดคำนวณ `AI TinyML` $\to$ `PL Poly` $\to$ `SC StdCurv`
- **จอยสติ๊กโยกลง (`WIO_5S_DOWN`):**
  - หน้า Calibrate: สั่งบันทึกจุดสารมาตรฐาน (Step Calib)
  - หน้า NPK / pH: สั่งอ่านค่าและบันทึกข้อมูลด่วน
- **จอยสติ๊กกดตรงกลาง (`WIO_5S_PRESS`):**
  - หน้า Calibrate: บันทึกค่าศูนย์เทียบน้ำกลั่น (Zero Blank Reference)
  - หน้าอื่น: สลับเปิด/ปิด ไฟแสงสีขาว (White LED) ตรวจสอบตัวอย่าง
- **ปุ่ม A, B, C (ด้านบนตัวเครื่อง):**
  - หน้า Calibrate: เลือกธาตุที่ต้องการเทียบมาตรฐาน (C=ไนโตรเจน 465nm, B=ฟอสฟอรัส 525nm, A=โพแทสเซียม 625nm)
  - หน้า NPK: สลับเปิด/ปิด หลอดไฟแมนนวล (C=น้ำเงิน, B=เขียว, A=แดง)

---

## 5. ทฤษฎีและแบบจำลองการคำนวณเคมีวิเคราะห์

### 5.1 แบบจำลอง TinyML Deep Neural Network
โครงข่ายประสาทเทียม Multi-Layer Perceptron ($6 	o 12 	o 8 	o 3$) พร้อมระบบชดเชยความขุ่น:
- เวกเตอร์คุณลักษณะนำเข้า 6 ตัว: $b_p, g_p, r_p, c_{	ext{ratio}}, 	ext{lux}_{	ext{norm}}, A_{	ext{est}}$
- คำนวณแบบ C++ Zero-Allocation ไม่ใช้หน่วยความจำฮีป
- ความเร็วการประมวลผล $12.4\ \mu	ext{s}$ ต่อการวัด

### 5.2 แบบจำลองพหุนามสากล (Classical Polynomial)
$$N \,(	ext{mg/kg}) = -185.42 + 8.234\,b_p - 0.0412\,b_p^2 + 0.000091\,b_p^3$$
$$P \,(	ext{mg/kg}) = -224.18 + 12.56\,g_p - 0.0823\,g_p^2$$
$$K \,(	ext{mg/kg}) = -18.92 + 1.842\,r_p + 0.0156\,r_p^2$$

### 5.3 แบบจำลองเส้นตรงมาตรฐานสด (In-Situ Standard Curve)
$$C_{	ext{sample}} = \max\left(0.0, \, \frac{A_{	ext{sample}} - c}{m}
ight)$$

---

## 6. ขั้นตอนการปฏิบัติการตรวจวัดธาตุอาหารในดิน (NPK Soil Testing)

1. **การเตรียมตัวอย่างดิน:** ชั่งตัวอย่างดินแห้ง 5 กรัม ผสมน้ำยาสกัดธาตุอาหาร เขย่าเป็นเวลา 5 นาที แล้วตั้งทิ้งไว้ให้ตกตะกอน หรือกรองผ่านกระดาษกรอง Whatman No. 42
2. **การทำปฏิกิริยาสี:** ดูดสารละลายใส 2 มิลลิลิตร ใส่ลงในหลอดทดลอง เติมน้ำยาทดสอบเฉพาะของ N, P หรือ K ตามคู่มือสารเคมี
3. **การเทียบศูนย์แบลงก์ (Blanking):** รินน้ำกลั่นหรือสารละลายสกัดเปล่าใส่หลอดคิวเวตต์ ใส่ลงในช่องวัด ปิดฝากันแสง แล้วกดปุ่มจอยสติ๊กตรงกลาง (`WIO_5S_PRESS`) ในหน้า Calibrate เพื่อตั้งค่าศูนย์
4. **การวัดตัวอย่าง:** นำหลอดคิวเวตต์บรรจุสารตัวอย่างใส่ลงในช่องวัด ปิดฝากันแสง หน้าจอ NPK Level Meter จะแสดงค่าความเข้มข้นของ N, P, K แบบเรียลไทม์ และบันทึกลงในไฟล์ `NPK.csv` บน microSD Card ทุกวินาที

---

## 7. ขั้นตอนการปฏิบัติการตรวจวัดสมบัติของเหลวและสเปกตรัมแสง (Liquid Optics & Spectral Metrology)

1. เลื่อนจอยสติ๊กไปที่หน้าจอที่ 6 หรือ 7 (**Page 6: Matrix / Page 7: 5-Band Spectral Scan `[7/8]`**)
2. บรรจุน้ำกลั่นบริสุทธิ์ลงในหลอดคิวเวตต์ ใส่ลงในช่องวัด ปิดฝากันแสง แล้วกด **จอยสติ๊กตรงกลาง (`WIO_5S_PRESS`)** ในหน้า Calibrate เพื่อตั้งค่าอ้างอิง Zero Blanking ($I_0$) ทุกช่องคลื่น ($n=1.3330, \rho=0.9982\text{ g/cm}^3$)
3. เทน้ำกลั่นออก ซับหลอดคิวเวตต์ให้แห้ง แล้วบรรจุตัวอย่างของเหลวที่ต้องการตรวจวัด (เช่น น้ำชลประทาน น้ำหมักชีวภาพ สารละลายธาตุอาหารพืช)
4. กด **จอยสติ๊กโยกลง (`WIO_5S_DOWN`)** ในหน้า `[7/8]` เพื่อสั่งรันระบบกวาดสเปกตรัมหลายช่วงคลื่น (Auto-Wavelength Sweep 465–625 nm)
5. เครื่องจะประมวลผลและแสดงผลการวิเคราะห์บนหน้าจอทันที:
   - **ดัชนีหักเหของแสง ($n$):** คำนวณจากทัศนศาสตร์ฟิสิกส์ความละเอียดทศนิยม 4 ตำแหน่ง
   - **ความหนาแน่นของของเหลว ($\rho$):** ในหน่วย $\text{g/cm}^3$
   - **ความเข้มข้นสารละลายและน้ำตาล ($^\circ\text{Bx}$):** ในหน่วย Brix Degree ตามเกณฑ์ ICUMSA
   - **ระดับความขุ่น (Clarity):** จำแนกเป็น `CLEAR`, `SLIGHT TURBID`, หรือ `TURBID`
   - **สเปกตรัมการดูดกลืนแสง:** กราฟแท่งและตัวเลข Absorbance รายช่องคลื่น $465, 500, 525, 590, 625\text{ nm}$
6. ข้อมูลจะถูกบันทึกต่อท้ายไฟล์ `SPECTRUM.csv` และ `LIQUID_LOG.csv` บน microSD Card โดยอัตโนมัติ

---

## 8. การเทียบมาตรฐานและการสร้างเส้นโค้งมาตรฐาน (In-Situ Standard Curve Wizard)

1. เลื่อนจอยสติ๊กไปที่หน้าจอที่ 8 (**Page 8: Multi-Point Calibration Wizard `[8/8]`**)
2. เลือกธาตุอาหารที่ต้องการเทียบมาตรฐานผ่านปุ่มลัดด้านบน:
   - **กดปุ่ม C (ซ้าย):** ไนโตรเจน (N - สลับไฟ Blue LED 465 nm อัตโนมัติ)
   - **กดปุ่ม B (กลาง):** ฟอสฟอรัส (P - สลับไฟ Red LED 625 nm สำหรับ Molybdenum Blue อัตโนมัติ)
   - **กดปุ่ม A (ขวา):** โพแทสเซียม (K - สลับไฟ Red LED 625 nm สำหรับ Turbidimetry อัตโนมัติ)
3. **เทียบศูนย์แบลงก์:** ใส่หลอดน้ำกลั่นบริสุทธิ์ ปิดฝากันแสง แล้วกด **จอยสติ๊กตรงกลาง (`WIO_5S_PRESS`)**
4. **วัดจุดมาตรฐาน 5 จุดความเข้มข้น:**
   - ใส่สารละลายมาตรฐานความเข้มข้น $0\text{ mg/kg}$ แล้วกด **จอยสติ๊กโยกลง (`WIO_5S_DOWN`)**
   - เปลี่ยนสารละลายมาตรฐานเป็นความเข้มข้น $20, 40, 80, 160\text{ mg/kg}$ ตามลำดับ แล้วกดโยกลงทีละจุดจนครบ 5 จุด
5. **การคำนวณและประเมินผล:**
   - ระบบคำนวณการถดถอยเชิงเส้นตรง OLS (Ordinary Least Squares) บนฮาร์ดแวร์ ARM Cortex-M4F FPU อัตโนมัติ
   - พล็อตกราฟเส้นโค้งมาตรฐานและจุดพิกัดสารละลายสดบนหน้าจอ LCD
   - รายงานค่าสัมประสิทธิ์การตัดสินใจ $R^2$, ความชัน $m$, จุดตัดแกน $c$, ขีดจำกัดตรวจวัด LOD, และขีดจำกัดตรวจหาปริมาณ LOQ ตามมาตรฐาน IUPAC/ISO 17025
   - บันทึกพารามิเตอร์ลงหน่วยความจำถาวรและบันทึกประวัติลงไฟล์ `CALIB_LOG.csv` บน microSD Card ทันที

---

## 9. โครงสร้างการบันทึกข้อมูลบนการ์ดหน่วยความจำ microSD Card

ระบบรองรับการบันทึกข้อมูลแบบ Quadruple Logging 4 ไฟล์:

| ชื่อไฟล์ | ชนิดข้อมูล | โครงสร้างคอลัมน์ |
| :--- | :--- | :--- |
| `NPK.csv` | ค่าความเข้มข้นดินต่อเนื่อง | `Sample,Time,Blue,Green,Red,Clear,N_mg_kg,P_mg_kg,K_mg_kg,Model` |
| `SPECTRUM.csv` | สเปกตรัมการดูดกลืนแสง | `ScanID,Time,A_465nm,A_500nm,A_525nm,A_590nm,A_625nm,Peak_nm,Peak_A,Warning` |
| `CALIB_LOG.csv` | ประวัติการเทียบมาตรฐาน | `Time,Nutrient,Wavelength_nm,Slope_m,Intercept_c,R2,s_yx,LOD_mg_kg,LOQ_mg_kg` |
| `LIQUID_LOG.csv` | สมบัติเชิงแสงของของเหลว | `Time,n_Index,Density_g_cm3,Brix_deg,Transmittance_pct,A_465nm,A_500nm,A_525nm,A_590nm,A_625nm,Peak_nm,Clarity` |

---

## 10. การบำรุงรักษาและการแก้ไขปัญหาเบื้องต้น

| ปัญหาที่พบ | สาเหตุที่เป็นไปได้ | แนวทางการแก้ไข |
| :--- | :--- | :--- |
| หน้าจอไม่แสดงผลฟอนต์ไทย | ไม่พบไฟล์ `THSarabunPSK30.vlw` บน microSD | วางไฟล์ `.vlw` ที่รูทของการ์ด microSD หรือระบบจะสลับใช้ฟอนต์อังกฤษขนาดใหญ่แทนอัตโนมัติ |
| เซนเซอร์ไม่ตรวจพบข้อมูล | สายสัญญาณ I2C หลวม | ตรวจสอบการเสียบสายพอร์ต Grove ขวาให้แน่นหนา |
| ค่าการดูดกลืนแสงสูงผิดปกติ ($A > 1.50$) | สารละลายตัวอย่างเข้มข้นเกินย่านเชิงเส้น | เจือจางสารละลายตัวอย่างด้วยน้ำกลั่นในอัตราส่วน 1:5 |
| ค่าการวัดผันผวน | คิวเวตต์มีคราบหรือฟองอากาศ | เช็ดผิวนอกคิวเวตต์ด้วยกระดาษเช็ดเลนส์ และเคาะเบาๆ ให้ฟองอากาศลอยหมด |
| พอร์ต USB ไม่ตอบสนอง | พอร์ตอยู่ในสถานะค้าง | เลื่อนสวิตช์เปิดปิดด้านข้างลง 2 ครั้งอย่างรวดเร็วเพื่อเข้า Bootloader แล้วแฟลชเฟิร์มแวร์ใหม่ |

---

## 11. การเชื่อมต่อเครือข่าย Wi-Fi และสถาปัตยกรรม JSON REST Server

เครื่องสเปกโทรโฟโตมิเตอร์ Wio Terminal ติดตั้งโมดูลเครือข่ายไร้สาย Realtek RTL8720DN ที่รองรับการทำงานสองย่านความถี่ (2.4 GHz / 5.0 GHz) โดยเฟิร์มแวร์บรรจุเซิร์ฟเวอร์ HTTP REST API ขนาดเล็ก (Micro-Web-Server) บนพอร์ต 80 เพื่อให้บริการแลกเปลี่ยนข้อมูลในรูปแบบมาตรฐาน JSON

### 11.1 โหมดการทำงานของ Wi-Fi
1. **Station Mode (STA):** บอร์ดจะทำการเชื่อมต่อกับ Wi-Fi Router หรือ Mobile Hotspot อัตโนมัติ โดยระบุชื่อ SSID และรหัสผ่านใน `WiFi_Server_Engine.h`
2. **SoftAP Mode (Fallback):** หากอยู่นอกพื้นที่เครือข่ายหรือไม่สามารถเชื่อมต่อได้ บอร์ดจะสลับไปปล่อยสัญญาณ Access Point ชื่อ `NPK-Spectrometer-AP` (IP: `192.168.4.1`) โดยอัตโนมัติ

### 11.2 รายการชุดคำสั่ง REST API (JSON Protocol)
- `GET /api/status` ตรวจสอบสถานะการทำงาน แรงดันไฟฟ้า เซนเซอร์ และค่า RSSI
- `GET /api/latest` ดึงผลการวัดล่าสุด (N, P, K, $n$, $\rho$, Brix, Transmittance, Absorbance 5 ช่องคลื่น)
- `GET /api/history` สตรีมประวัติข้อมูลทั้งหมดในไฟล์ `DATA_LOG.json` จากการ์ด microSD
- `POST /api/scan-soil` สั่งให้เครื่องทำการสแกนดินแบบไร้สาย
- `POST /api/scan-liquid` สั่งให้เครื่องทำการสแกนของเหลวแบบไร้สาย
- `POST /api/calibrate` สั่งเทียบศูนย์แบลงก์ (Blank Calibration)

---

## 12. ระบบเว็บแอปพลิเคชันแดชบอร์ดและฐานข้อมูล JSON (Web Dashboard)

เพื่อความสะดวกในการปฏิบัติงานภาคสนามและในห้องปฏิบัติการ ได้จัดทำ Web Dashboard แบบ Responsive Glassmorphic หน้าตาสวยงามระดับพรีเมียมในโฟลเดอร์ `web/`

### 12.1 การเปิดใช้งานเว็บแอปพลิเคชัน
ผู้ใช้งานสามารถเปิดใช้งานแดชบอร์ดได้ทันทีผ่าน 2 ช่องทาง:
1. **เปิดผ่าน Local HTTP Server:**
   ```bash
   python3 -m http.server 5555 --directory web
   ```
   แล้วเข้าใช้งานผ่านเว็บเบราว์เซอร์ที่ `http://localhost:5555`
2. **เปิดไฟล์ `web/index.html`:** สามารถเปิดผ่านเบราว์เซอร์โดยตรง หรือนำขึ้น GitHub Pages

### 12.2 ฟังก์ชันเด่นของระบบแดชบอร์ด
- **Live Telemetry & Gauges:** แสดงค่า N, P, K และสมบัติของเหลว ($n$, $\rho$, Brix, Clarity) แบบเรียลไทม์
- **Dynamic 5-Wavelength Absorbance Chart:** กราฟิกสเปกตรัมแสง 5 ช่วงคลื่นพร้อมเส้นโค้ง Bézier นุ่มนวลและหมุดแสดงค่าการดูดกลืนแสง
- **Interactive JSON Database Manager:**
  - ตารางแสดงประวัติข้อมูลการวัดทั้งหมด พร้อมระบบค้นหา (Search) และตัวกรองประเภท
  - ปุ่ม **{ } JSON** เพื่อดูโครงสร้างข้อมูลดิบแบบละเอียด
  - ปุ่ม **ส่งออก JSON (Export JSON)** ดาวน์โหลดฐานข้อมูลเป็นไฟล์ `.json`
  - ปุ่ม **นำเข้า JSON (Import JSON)** โหลดฐานข้อมูลเดิมกลับเข้ามาวิเคราะห์
  - ปุ่ม **ส่งออก CSV (Export CSV)** เพื่อนำไปเปิดใน Microsoft Excel หรือโปรแกรมทางสถิติ
- **Mock Demo Mode:** มีโหมดจำลองออฟไลน์ในตัว ทำให้สามารถทดสอบฟังก์ชันการทำงาน กราฟิก และฐานข้อมูลได้ทันทีแม้อยู่นอกห้องปฏิบัติการ

---
**จัดทำโดย หน่วยวิจัยเกษตรดิจิทัล JC_AI_SciRBRU (Digital Agriphysics & AI Research Unit)**  
มหาวิทยาลัยราชภัฏรำไพพรรณี จังหวัดจันทบุรี

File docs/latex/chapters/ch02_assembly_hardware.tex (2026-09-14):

\chapter{การออกแบบและประกอบชิ้นส่วนฮาร์ดแวร์}
\label{chap:ch02}

\section*{แผนบริหารการสอนประจำบทที่ 2}
\addcontentsline{toc}{section}{แผนบริหารการสอนประจำบทที่ 2}

\begin{planbox}{หัวข้อเนื้อหาประจำบท}
\begin{enumerate}[leftmargin=1.5em, itemsep=1pt]
    \item สถาปัตยกรรมฮาร์ดแวร์และคุณสมบัติของไมโครคอนโทรลเลอร์ ATSAMD51
    \item รายการอุปกรณ์และโมดูลตรวจวัดแสง TCS34725 ร่วมกับหลอดไฟ WS2812B
    \item การออกแบบทางเดินแสงของช่องใส่คิวเวตต์เพื่อลดการสะท้อนและการกระเจิง
    \item ขั้นตอนการประกอบกลไกและการต่อขาสัญญาณดิจิทัล
\end{enumerate}
\end{planbox}

\begin{planbox}{วัตถุประสงค์เชิงพฤติกรรม}
\begin{enumerate}[leftmargin=1.5em, itemsep=1pt]
    \item ระบุหน้าที่และตำแหน่งของขาสัญญาณควบคุมในระบบสเปกโทรโฟโตมิเตอร์ได้อย่างถูกต้อง
    \item อธิบายหลักการจัดวางแนวแกนแสงระหว่างแหล่งกำเนิด หลอดคิวเวตต์ และเซนเซอร์ได้อย่างสมบูรณ์
    \item ปฏิบัติการประกอบและทดสอบการเชื่อมต่อวงจรฮาร์ดแวร์ได้อย่างถูกต้องปลอดภัย
\end{enumerate}
\end{planbox}

\begin{planbox}{กิจกรรมการเรียนการสอน}
\begin{enumerate}[leftmargin=1.5em, itemsep=1pt]
    \item การบรรยายและสาธิตการเชื่อมต่อสายสัญญาณผ่านพอร์ต Grove
    \item ปฏิบัติการประกอบชิ้นส่วนฮาร์ดแวร์ลงในกล่องบรรจุ 3D Printed Enclosure
    \item การตรวจสอบความถูกต้องของระบบไฟฟ้าและสัญญาณ I2C ก่อนการจ่ายไฟ
\end{enumerate}
\end{planbox}

\begin{planbox}{สื่อการเรียนการสอน}
\begin{enumerate}[leftmargin=1.5em, itemsep=1pt]
    \item บอร์ด Seeed Studio Wio Terminal พร้อมสายเชื่อมต่อ Grove
    \item โมดูลเซนเซอร์ Adafruit TCS34725 และโมดูลไฟ Grove NeoPixel WS2812B
    \item ชุดโครงสร้างกล่องบรรจุ 3 มิติและแท่นยึดคิวเวตต์ขนาด 10 มิลลิเมตร
\end{enumerate}
\end{planbox}

\begin{planbox}{การวัดและประเมินผล}
\begin{enumerate}[leftmargin=1.5em, itemsep=1pt]
    \item การประเมินทักษะการประกอบวงจรและการจัดสายสัญญาณอย่างเป็นระเบียบ
    \item การทดสอบการตรวจพบอุปกรณ์ I2C ผ่านโปรแกรมตรวจสอบที่อยู่บัส
    \item การตรวจความถูกต้องของการตอบคำถามทบทวนท้ายบทที่ 2
\end{enumerate}
\end{planbox}

\clearpage

\section{รายการอุปกรณ์และโมดูลฮาร์ดแวร์}
อุปกรณ์ที่ใช้ในการประกอบและสร้างเครื่องสเปกโทรโฟโตมิเตอร์ประกอบด้วยรายการดังแสดงในตารางที่ \ref{tab:components}

\begin{table}[H]
    \caption{รายการอุปกรณ์และโมดูลฮาร์ดแวร์}
    \label{tab:components}
    \begin{tabularx}{\textwidth}{p{3.2cm}p{4.2cm}X}
        \toprule
        \textbf{อุปกรณ์} & \textbf{รุ่นหรือรหัสสินค้า} & \textbf{บทบาทหน้าที่ในระบบ} \\
        \midrule
        บอร์ดประมวลผล & Seeed Studio Wio Terminal & ไมโครคอนโทรลเลอร์ ATSAMD51 พร้อมจอ LCD 2.4 นิ้ว \\
        เซนเซอร์ตรวจวัดแสง & Adafruit TCS34725 & เซนเซอร์ตรวจวัดแสงสีและค่าความสว่างแบบ I2C \\
        แหล่งกำเนิดแสงสี & Grove RGB LED (WS2812B) & ไดโอดเปล่งแสงควบคุมสีแบบดิจิทัลความยาวคลื่นแม่นยำ \\
        ช่องใส่หลอดทดลอง & Cuvette Holder 10 mm & แท่นยึดหลอดคิวเวตต์มาตรฐานทางเดินแสง 10 มิลลิเมตร \\
        สายเชื่อมต่อข้อมูล & Grove 4-Pin Cable & สายส่งสัญญาณดิจิทัลและสายจ่ายพลังงานไฟฟ้า \\
        การ์ดหน่วยความจำ & microSD Card Class 10 & อุปกรณ์บันทึกผลการวัดลงไฟล์ข้อมูล 4 รูปแบบ (NPK.csv, SPECTRUM.csv, CALIB\_LOG.csv, LIQUID\_LOG.csv) \\
        โครงสร้างตัวเครื่อง & 3D Printed Enclosure & กล่องบรรจุอุปกรณ์ภายนอกออกแบบด้วยเส้นใย PLA+ \\
        \bottomrule
    \end{tabularx}
\end{table}

\section{แผนภาพการต่อวงจรและขาสัญญาณ}
การเชื่อมต่อสัญญาณระหว่างบอร์ด Wio Terminal กับโมดูลเซนเซอร์และแหล่งกำเนิดแสง แสดงรายละเอียดตามตารางที่ \ref{tab:pinout}

\begin{table}[H]
    \caption{การกำหนดขาสัญญาณและการเชื่อมต่ออุปกรณ์}
    \label{tab:pinout}
    \begin{tabularx}{\textwidth}{p{3.0cm}p{3.0cm}p{3.0cm}X}
        \toprule
        \textbf{อุปกรณ์ภายนอก} & \textbf{พอร์ต Wio Terminal} & \textbf{ขาสัญญาณไมโคร} & \textbf{คำอธิบายการเชื่อมต่อ} \\
        \midrule
        TCS34725 (SDA) & Grove พอร์ตขวา & ขา SDA (PA17) & ส่งสัญญาณข้อมูล I2C บัสความเร็ว 100 kHz \\
        TCS34725 (SCL) & Grove พอร์ตขวา & ขา SCL (PA16) & ส่งสัญญาณนาฬิกา I2C บัสความเร็ว 100 kHz \\
        TCS34725 (VCC) & Grove พอร์ตขวา & ขา 3V3 หรือ 5V & แหล่งจ่ายพลังงานไฟฟ้ากระแสตรง 3.3 โวลต์ \\
        TCS34725 (GND) & Grove พอร์ตขวา & ขา GND & กราวด์ร่วมของระบบ \\
        \midrule
        RGB LED (DIN)  & Grove พอร์ตซ้าย & ขา D0 (PB08) & ขาสัญญาณข้อมูลควบคุมหลอด NeoPixel WS2812B \\
        RGB LED (VCC)  & Grove พอร์ตซ้าย & ขา 5V        & จ่ายแรงดันไฟฟ้าเลี้ยงหลอดไฟ 5 โวลต์ \\
        RGB LED (GND)  & Grove พอร์ตซ้าย & ขา GND       & กราวด์ร่วมของหลอดไฟ \\
        \midrule
        ปุ่มกด A       & ด้านบนตัวเครื่อง & WIO\_KEY\_A (28) & ปุ่มด้านขวาสุด ควบคุมการเปิดปิดแสงสีแดง \\
        ปุ่มกด B       & ด้านบนตัวเครื่อง & WIO\_KEY\_B (29) & ปุ่มตรงกลาง ควบคุมการเปิดปิดแสงสีเขียว \\
        ปุ่มกด C       & ด้านบนตัวเครื่อง & WIO\_KEY\_C (30) & ปุ่มด้านซ้ายสุด ควบคุมการเปิดปิดแสงสีน้ำเงิน \\
        จอยสติ๊กกลาง   & ด้านหน้าตัวเครื่อง & WIO\_5S\_PRESS (35) & กดลงตรงกลาง ควบคุมการเปิดปิดแสงสีขาว \\
        \bottomrule
    \end{tabularx}
\end{table}

\section{การออกแบบทางเดินแสงและกล่องบรรจุ 3 มิติ}
กล่องบรรจุอุปกรณ์ภายนอก (Enclosure) และแท่นยึดคิวเวตต์ได้รับการขึ้นรูปด้วยเครื่องพิมพ์สามมิติ (3D Printing) โดยใช้วัสดุเส้นใย PLA+ สีดำด้าน (Matte Black) เพื่อลดการสะท้อนแสงภายในห้องวัด (Internal Reflection Reduction) โดยมีคุณลักษณะทางทัศนศาสตร์ที่สำคัญ
\begin{itemize}[leftmargin=1.5em, itemsep=2pt]
    \item \textbf{แนวแกนแสงตรง (Coaxial Optical Path):} กึ่งกลางหลอดไฟ WS2812B ช่องคิวเวตต์ และเซนเซอร์ TCS34725 อยู่ในระดับความสูงเดียวกันที่ 15.0 มิลลิเมตรจากฐาน
    \item \textbf{ช่องจำกัดลำแสง (Collimating Aperture):} ขนาดเส้นผ่านศูนย์กลาง 3.0 มิลลิเมตร ติดตั้งระหว่างหลอด LED กับผิวคิวเวตต์ เพื่อให้ได้ลำแสงขนานที่ตั้งฉากกับผนังคิวเวตต์
    \item \textbf{ฝาครอบกันแสงภายนอก (Light-Tight Lid):} มีขอบประกบแบบเขี้ยวซ้อน (Baffle Joint) ป้องกันแสงรอบข้าง (Ambient Light Stray) เล็ดลอดเข้าสู่เซนเซอร์ได้อย่างสมบูรณ์
\end{itemize}

\section{ขั้นตอนการประกอบชิ้นส่วนกลไก}
การประกอบอุปกรณ์ลงในกล่องบรรจุ 3D Printed Enclosure มีขั้นตอนดังต่อไปนี้

\begin{enumerate}[leftmargin=1.5em, itemsep=3pt]
    \item นำแท่นยึดหลอดคิวเวตต์ (Cuvette Holder) ติดตั้งเข้ากับฐานล่างของกล่อง โดยหันด้านช่องส่องแสงให้ตรงกับตำแหน่งติดตั้งโมดูลหลอดไฟและเซนเซอร์
    \item ติดตั้งโมดูลหลอดไฟ Grove RGB LED เข้ากับด้านข้างช่องคิวเวตต์ โดยให้ผิวหน้าของหลอด LED ขนานกับผนังคิวเวตต์และกั้นแสงรบกวนจากภายนอก
    \item ติดตั้งโมดูลเซนเซอร์ TCS34725 ในตำแหน่งตรงข้ามกับหลอด LED ในแนวแกนแสงเดียวกัน เพื่อให้รับลำแสงที่ทะลุผ่านหลอดคิวเวตต์ได้อย่างสมบูรณ์
    \item เสียบสาย Grove 4-Pin จากหลอด LED เข้าสู่พอร์ต Grove ด้านซ้าย (D0) ของบอร์ด Wio Terminal
    \item เสียบสาย Grove 4-Pin จากเซนเซอร์ TCS34725 เข้าสู่พอร์ต Grove ด้านขวา (I2C) ของบอร์ด Wio Terminal
    \item ประกอบบอร์ด Wio Terminal เข้ากับฝาครอบด้านหน้า ขันสกรูยึดให้แน่นหนา และตรวจเช็คการขยับของปุ่มกด A, B, C และจอยสติ๊กด้านหน้าให้เคลื่อนไหวได้อย่างอิสระ
\end{enumerate}

\section*{บทสรุปประจำบทที่ 2}
\addcontentsline{toc}{section}{บทสรุปประจำบทที่ 2}
การออกแบบโครงสร้างฮาร์ดแวร์ของเครื่องสเปกโทรโฟโตมิเตอร์คำนึงถึงความแม่นยำทางทัศนศาสตร์และความสะดวกในการพกพา การใช้พอร์ต Grove อำนวยความสะดวกในการเชื่อมต่อเซนเซอร์ I2C และหลอดดิจิทัล NeoPixel อย่างแน่นหนา ในขณะที่ห้องวัดแสงที่พิมพ์ด้วยเส้นใยสีดำด้านพร้อมช่องจำกัดลำแสงช่วยลดสัญญาณรบกวนและแสงกระเจิง ส่งผลให้สัญญาณการวัดมีความเสถียรและทำซ้ำได้สูง

\section*{คำถามทบทวนท้ายบทที่ 2}
\addcontentsline{toc}{section}{คำถามทบทวนท้ายบทที่ 2}
\begin{enumerate}[leftmargin=1.5em, itemsep=3pt]
    \item เหตุใดการออกแบบแท่นยึดคิวเวตต์จึงต้องใช้วัสดุสีดำด้าน และหากใช้วัสดุสีขาวสะท้อนแสงจะส่งผลกระทบต่อค่าการดูดกลืนแสงอย่างไร
    \item สัญญาณนาฬิกา I2C ที่ความเร็ว 100 kHz เหมาะสมกับการอ่านค่าจากเซนเซอร์ TCS34725 หรือไม่ เพราะเหตุใด
    \item จงอธิบายบทบาทของช่องจำกัดลำแสง (Collimating Aperture) ที่อยู่ระหว่างหลอดไฟ LED กับคิวเวตต์
    \item หากเซนเซอร์ TCS34725 ไม่อยู่ในแนวแกนเดียวกับหลอด LED จะเกิดความคลาดเคลื่อนเชิงแสงในลักษณะใด
\end{enumerate}

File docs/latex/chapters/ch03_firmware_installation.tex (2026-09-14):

\chapter{การติดตั้งเฟิร์มแวร์และการตั้งค่าซอฟต์แวร์}
\label{chap:ch03}

\section*{แผนบริหารการสอนประจำบทที่ 3}
\addcontentsline{toc}{section}{แผนบริหารการสอนประจำบทที่ 3}

\begin{planbox}{หัวข้อเนื้อหาประจำบท}
\begin{enumerate}[topsep=2pt, itemsep=1pt, partopsep=0pt, parsep=0pt, leftmargin=1.5em]
    \item สถาปัตยกรรมเฟิร์มแวร์แบบโมดูลาร์บนชิป ATSAMD51 ARM Cortex-M4F
    \item การติดตั้งและการกำหนดค่าไลบรารีระบบควบคุมจอภาพและเซนเซอร์
    \item สถาปัตยกรรมการเชื่อมต่อเครือข่ายไร้สาย Wi-Fi และ Embedded JSON REST Server
    \item การคอมไพล์โปรแกรมผ่าน Arduino CLI และเทคนิคการอัปโหลดเฟิร์มแวร์
    \item การกู้คืนระบบผ่านโหมด Bootloader และการจัดการหน่วยความจำ Flash
\end{enumerate}
\end{planbox}

\begin{planbox}{วัตถุประสงค์เชิงพฤติกรรม}
\begin{enumerate}[topsep=2pt, itemsep=1pt, partopsep=0pt, parsep=0pt, leftmargin=1.5em]
    \item อธิบายโครงสร้างสถาปัตยกรรมซอฟต์แวร์และการทำงานร่วมกันของแต่ละเอนจินได้อย่างถูกต้อง
    \item ติดตั้งไลบรารีที่จำเป็นและแก้ไขคอนฟิกูเรชันของบอร์ด Wio Terminal ได้อย่างสมบูรณ์
    \item กำหนดค่าการเชื่อมต่อเครือข่าย Wi-Fi ทั้งโหมด Station และ SoftAP ได้อย่างถูกต้อง
    \item คอมไพล์โปรแกรมและกู้คืนบอร์ดผ่านโหมด Bootloader เมื่อเกิดข้อขัดข้องได้อย่างชำนาญ
\end{enumerate}
\end{planbox}

\newpage

\begin{planbox}{วิธีสอนและกิจกรรมการเรียนการสอน}
\begin{enumerate}[topsep=2pt, itemsep=1pt, partopsep=0pt, parsep=0pt, leftmargin=1.5em]
    \item การบรรยายเชิงวิชาการประกอบสไลด์และไดอะแกรมการไหลของข้อมูล (Data Flow Diagram)
    \item การฝึกปฏิบัติการเขียนคำสั่งคอมไพล์ผ่านระบบ Command Line Interface (Arduino CLI)
    \item กิจกรรมการทดลองเชื่อมต่อบอร์ด Wio Terminal กับเครือข่าย Wi-Fi และทดสอบคำสั่ง REST API
    \item การจำลองสถานการณ์พอร์ตสื่อสารขัดข้องและฝึกปฏิบัติการกู้คืนด้วยระบบ Double Touch Reset
\end{enumerate}
\end{planbox}

\begin{planbox}{สื่อการเรียนการสอน}
\begin{enumerate}[topsep=2pt, itemsep=1pt, partopsep=0pt, parsep=0pt, leftmargin=1.5em]
    \item เครื่องคอมพิวเตอร์พร้อมติดตั้งโปรแกรม Arduino CLI และไดรเวอร์ USB-to-Serial
    \item บอร์ด Seeed Studio Wio Terminal พร้อมสายเชื่อมต่อ USB Type-C High-Speed
    \item ไฟล์ซอร์สโค้ดเฟิร์มแวร์ spectrometer\_npk2026 และชุดไลบรารีภาษา C/C++
    \item เอกสารคู่มือปฏิบัติการและเว็บแอปพลิเคชันแดชบอร์ดจำลองบนเครือข่ายท้องถิ่น
\end{enumerate}
\end{planbox}

\begin{planbox}{การวัดและประเมินผล}
\begin{enumerate}[topsep=2pt, itemsep=1pt, partopsep=0pt, parsep=0pt, leftmargin=1.5em]
    \item การประเมินผลสัมฤทธิ์จากการคอมไพล์และอัปโหลดโปรแกรมลงบอร์ดจริง
    \item การตรวจสอบความสามารถในการตอบสนองของเซิร์ฟเวอร์ JSON REST API ผ่านเครือข่าย Wi-Fi
    \item การตรวจรายงานผลการกู้คืนระบบ Bootloader และการทดสอบความรู้ท้ายบทเรียน
\end{enumerate}
\end{planbox}

\clearpage

\section{สถาปัตยกรรมเฟิร์มแวร์บน ATSAMD51}
เฟิร์มแวร์ของเครื่องสเปกโทรโฟโตมิเตอร์พัฒนาขึ้นบนระบบนิเวศ Arduino โดยปรับแต่งให้ทำงานบนสถาปัตยกรรม ARM Cortex-M4F ของไมโครคอนโทรลเลอร์ Microchip ATSAMD51P19A บนบอร์ด Seeed Studio Wio Terminal พร้อมระบบบริหารจัดการหน่วยความจำและจอแสดงผลที่มีประสิทธิภาพสูง โครงสร้างโค้ดเป็นแบบโมดูลาร์ (Modular Architecture) แยกการคำนวณออกเป็นเอนจินเฉพาะ
\begin{itemize}[leftmargin=1.5em, itemsep=2pt]
    \item \texttt{TinyML\_Model.h} โครงข่ายประสาทเทียม Multi-Layer Perceptron ($6 \to 12 \to 8 \to 3$)
    \item \texttt{Calibration\_Engine.h} การวิเคราะห์การถดถอยเชิงเส้นตรง OLS, $R^2$, LOD, LOQ
    \item \texttt{Spectrum\_Engine.h} การสแกนสเปกตรัมแสงหลายช่วงคลื่นและพล็อตกราฟิก 2D
    \item \texttt{Liquid\_Engine.h} การคำนวณดัชนีหักเห ($n$), ความหนาแน่น ($\rho$), Brix ($^\circ\text{Bx}$) และระดับความขุ่น
    \item \texttt{WiFi\_Server\_Engine.h} สถาปัตยกรรมเซิร์ฟเวอร์ HTTP REST API และการบันทึกฐานข้อมูล JSON
\end{itemize}

\section{ไลบรารีที่จำเป็นสำหรับระบบ}
การพัฒนาและคอมไพล์โปรแกรมต้องการไลบรารีมาตรฐานดังต่อไปนี้

\begin{enumerate}[leftmargin=1.5em, itemsep=3pt]
    \item \textbf{Seeed\_Arduino\_LCD} ไลบรารีควบคุมจอแสดงผล TFT LCD ความละเอียด 320x240 พิกเซลผ่านบัส SPI3 เฉพาะตัวของ Wio Terminal
    \item \textbf{Adafruit\_TCS34725} ไลบรารีสื่อสารกับเซนเซอร์วัดค่าสีแบบ I2C ควบคุมเวลาการประมวลผล (Integration Time) และเกนขยายสัญญาณ
    \item \textbf{Adafruit\_NeoPixel} ไลบรารีขับสัญญาณดิจิทัลควบคุมโมดูลหลอดไฟ RGB WS2812B
    \item \textbf{Seeed\_Arduino\_FS และ Seeed\_SD} ไลบรารีจัดการระบบไฟล์และบันทึกข้อมูลลงในการ์ดหน่วยความจำ microSD Card
    \item \textbf{rpcWiFi} ไลบรารีควบคุมระบบเครือข่ายไร้สายผ่านชิป Realtek RTL8720DN Dual-Band 2.4/5.0 GHz
\end{enumerate}

\section{ระบบเครือข่าย Wi-Fi และสถาปัตยกรรม Embedded JSON REST Server}
Wio Terminal มาพร้อมโมดูลเครือข่ายไร้สาย Realtek RTL8720DN ที่รองรับการทำงานทั้งโหมดไคลเอนต์ (Station Mode: STA) และโหมดปล่อยสัญญาณ (SoftAP Mode) โดยเฟิร์มแวร์ได้ติดตั้ง Embedded Micro-Web-Server บนพอร์ต 80 ซึ่งสื่อสารด้วยข้อมูลมาตรฐาน JSON พร้อมเปิดใช้งานระบบ Cross-Origin Resource Sharing (CORS) ทำให้ Web Dashboard สามารถเชื่อมต่อเข้ามาดึงข้อมูลหรือสั่งการได้จากระยะไกล

ชุดคำสั่ง REST API ที่รองรับในตัวเครื่อง
\begin{itemize}[leftmargin=1.5em, itemsep=2pt]
    \item \texttt{GET /api/status} รายงานสถานะเครื่อง กำลังไฟ เซนเซอร์ ค่า RSSI และหมายเลข IP Address
    \item \texttt{GET /api/latest} ส่งข้อมูลผลการวัดล่าสุด (N, P, K, $n$, $\rho$, Brix, Absorbance 5 ช่องคลื่น)
    \item \texttt{GET /api/history} สตรีมข้อมูลประวัติการวัดทั้งหมดจากไฟล์ \texttt{DATA\_LOG.json} บน microSD Card
    \item \texttt{POST /api/scan-soil} ส่งคำสั่งสั่งให้เครื่องสแกนธาตุอาหารดินแบบไร้สาย
    \item \texttt{POST /api/scan-liquid} ส่งคำสั่งสั่งให้เครื่องสแกนสมบัติของเหลวแบบไร้สาย
    \item \texttt{POST /api/calibrate} ส่งคำสั่งสั่งตั้งค่าศูนย์ (Blank Calibration)
\end{itemize}

\section{คำสั่งคอมไพล์และอัปโหลดโปรแกรม}
ผู้ใช้งานสามารถคอมไพล์และอัปโหลดโปรแกรมผ่านโปรแกรม Arduino CLI บนระบบปฏิบัติการ macOS หรือ Linux โดยใช้ชุดคำสั่งดังต่อไปนี้

\begin{center}
\begin{minipage}{0.92\textwidth}
\begin{verbatim}
# Compile sketch for Wio Terminal
arduino-cli compile --fqbn Seeeduino:samd:seeed_wio_terminal \
    firmware/spectrometer_npk2026

# Upload sketch via USB port
arduino-cli upload -p /dev/cu.usbmodem2101 \
    --fqbn Seeeduino:samd:seeed_wio_terminal \
    firmware/spectrometer_npk2026
\end{verbatim}
\end{minipage}
\end{center}

\section{การกู้คืนระบบผ่านโหมด Bootloader}
กรณีที่เกิดปัญหาพอร์ต USB หลุดการเชื่อมต่อหรือไม่ตอบสนอง สามารถแก้ไขได้โดยการเลื่อนสวิตช์เปิดปิดด้านข้างตัวเครื่องลง 2 ครั้งอย่างรวดเร็ว (Double-click Touch Reset) เพื่อเข้าสู่โหมด Bootloader จากนั้นคัดลอกไฟล์ไบนารี \texttt{spectrometer\_npk2026.uf2} ไปวางในไดรฟ์ USB เสมือนที่ปรากฏขึ้น บอร์ดจะทำการรีบูตและรันเฟิร์มแวร์ใหม่โดยอัตโนมัติ

\section*{บทสรุปประจำบทที่ 3}
\addcontentsline{toc}{section}{บทสรุปประจำบทที่ 3}
การติดตั้งเฟิร์มแวร์บนบอร์ด Wio Terminal ต้องการไลบรารีเฉพาะทางด้านการจัดการจอแสดงผลและระบบไฟล์ การขยายขีดความสามารถด้วยโมดูล Wi-Fi และระบบบริการ JSON REST API ช่วยยกระดับเครื่องมือวัดสู่ระบบ IoT เกษตรอัจฉริยะ การคอมไพล์ผ่าน Arduino CLI ใช้พื้นที่ Flash Memory เพียงร้อยละ 28 ของความจุชิป ทำให้ระบบมีเสถียรภาพและรองรับการประมวลผลได้อย่างมีประสิทธิภาพ

\section*{คำถามทบทวนท้ายบทที่ 3}
\addcontentsline{toc}{section}{คำถามทบทวนท้ายบทที่ 3}
\begin{enumerate}[leftmargin=1.5em, itemsep=3pt]
    \item สถาปัตยกรรม REST API แบบ JSON บนไมโครคอนโทรลเลอร์ช่วยเพิ่มประโยชน์ในการประยุกต์ใช้งานภาคสนามอย่างไร
    \item หาก Wio Terminal ไม่สามารถเชื่อมต่อกับ Access Point หลักได้ ระบบจะเปลี่ยนไปทำงานในโหมดใด
    \item เหตุใดจึงต้องเปิดใช้งานส่วนหัว CORS (Cross-Origin Resource Sharing) ในคำสั่งตอบรับ HTTP ของ Wio Terminal
    \item จงอธิบายขั้นตอนการนำบอร์ด Wio Terminal เข้าสู่โหมด Bootloader เมื่อคอมพิวเตอร์ตรวจไม่พบพอร์ต Serial
\end{enumerate}

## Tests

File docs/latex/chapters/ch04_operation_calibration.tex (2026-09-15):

\chapter{คู่มือการปฏิบัติการและแบบจำลองการเทียบมาตรฐาน}
\label{chap:ch04}

\section*{แผนบริหารการสอนประจำบทที่ 4}
\addcontentsline{toc}{section}{แผนบริหารการสอนประจำบทที่ 4}

\begin{planbox}{หัวข้อเนื้อหาประจำบท}
\begin{enumerate}[leftmargin=1.5em, itemsep=1pt]
    \item สถาปัตยกรรมการสลับหน้าจอ 8 หน้าจอ (8-Screen Carousel UI)
    \item ระบบเปลี่ยนความยาวคลื่นแสงอัตโนมัติ (Auto-Wavelength Switching Engine)
    \item ระบบการวิเคราะห์ 3 โหมด: TinyML, แบบจำลองพหุนาม และเส้นโค้งมาตรฐานสด
    \item ทฤษฎีการถดถอยเชิงเส้นตรง OLS การประเมินค่า $R^2$, LOD และ LOQ
    \item การวิเคราะห์สมบัติเชิงแสงและความหนาแน่นของของเหลวตามเกณฑ์ ICUMSA
    \item ขั้นตอนการตรวจวัดตัวอย่างดินและของเหลวในภาคสนาม และการบันทึกข้อมูล 4 ไฟล์
\end{enumerate}
\end{planbox}

\begin{planbox}{วัตถุประสงค์เชิงพฤติกรรม}
\begin{enumerate}[leftmargin=1.5em, itemsep=1pt]
    \item อธิบายขั้นตอนการสลับหน้าจอ 8 หน้าจอและการควบคุมคำสั่งผ่านจอยสติ๊กได้อย่างถูกต้อง
    \item คำนวณค่าสถิติการถดถอย $m$, $c$, $R^2$, LOD และ LOQ ได้อย่างถูกต้องตามเกณฑ์ IUPAC
    \item ปฏิบัติการตรวจวัดธาตุอาหารดิน pH ดิน และสมบัติของเหลวได้อย่างถูกต้อง แม่นยำ
\end{enumerate}
\end{planbox}

\begin{planbox}{กิจกรรมการเรียนการสอน}
\begin{enumerate}[leftmargin=1.5em, itemsep=1pt]
    \item การสาธิตการใช้งานเครื่องสเปกโทรโฟโตมิเตอร์ครบทั้ง 8 หน้าจอ
    \item ปฏิบัติการสร้างเส้นโค้งมาตรฐาน 5 จุดความเข้มข้นสารละลาย NPK
    \item ปฏิบัติการสแกนสเปกตรัมของเหลวตัวอย่างและวิเคราะห์ดัชนีหักเหและความหนาแน่น
\end{enumerate}
\end{planbox}

\begin{planbox}{สื่อการเรียนการสอน}
\begin{enumerate}[leftmargin=1.5em, itemsep=1pt]
    \item เครื่องสเปกโทรโฟโตมิเตอร์ Wio Terminal และการ์ด microSD
    \item ชุดสารละลายมาตรฐาน N, P, K ความเข้มข้น 0, 20, 40, 80, 160 mg/kg
    \item สารละลายตัวอย่างของเหลวและน้ำกลั่นบริสุทธิ์สำหรับเทียบศูนย์
\end{enumerate}
\end{planbox}

\begin{planbox}{การวัดและประเมินผล}
\begin{enumerate}[leftmargin=1.5em, itemsep=1pt]
    \item การประเมินทักษะการเทียบศูนย์และการปฏิบัติการสแกนสเปกตรัม
    \item การตรวจสอบความถูกต้องของไฟล์ข้อมูล NPK.csv, CALIB\_LOG.csv และ LIQUID\_LOG.csv
    \item การตรวจความถูกต้องของการตอบคำถามทบทวนท้ายบทที่ 4
\end{enumerate}
\end{planbox}

\clearpage

\section{ระบบควบคุมหน้าจอและการนำทาง 8 หน้าจอ (8-Screen Carousel UI)}
การใช้งานเครื่องสเปกโทรโฟโตมิเตอร์ตรวจวัดธาตุอาหารในดิน NPK Level Meter 1.02 ได้รับการออกแบบสถาปัตยกรรมซอฟต์แวร์ให้รองรับระบบเมนู 8 หน้าจอหลักแบบหมุนวน (8-Screen Carousel UI) ดังแสดงในตารางที่ \ref{tab:screens_8_overview} และตารางที่ \ref{tab:controls_mapping}

\begin{table}[H]
\centering
\caption{สถาปัตยกรรมหน้าจอแสดงผล 8 หน้าจอ (8-Screen Carousel UI)}
\label{tab:screens_8_overview}
\begin{tabularx}{\textwidth}{cclX}
\toprule
\textbf{หน้า} & \textbf{รหัส} & \textbf{ชื่อหน้าจอ} & \textbf{ฟังก์ชันการทำงานและความยาวคลื่นแสง} \\
\midrule
1 & \texttt{[1/8]} & System Dashboard & ภาพรวมระบบ "สเปกโทรโฟโตมิเตอร์" (กึ่งกลางจอ), แบรนด์ \textbf{SpecJC +AI Analyzer} สี่สี (กึ่งกลางจอ), โหมด \textbf{AI TinyML}, นาฬิกา RTC, สถานะเซนเซอร์ \\
2 & \texttt{[2/8]} & Dedicated Nitrogen & วิเคราะห์ปริมาณไนโตรเจน (กึ่งกลางจอ สี Cyan), สลับไฟ \textbf{Blue 465 nm} อัตโนมัติ, ตัวอักษร N สี Magenta, หน่วย $\text{mg/kg}$ \\
3 & \texttt{[3/8]} & Dedicated Phosphorus & วิเคราะห์ปริมาณฟอสฟอรัส (กึ่งกลางจอ สี Green), สลับไฟ \textbf{Red 625 nm} อัตโนมัติ, ตัวอักษร P สี Cyan, หน่วย $\text{mg/kg}$ ($x=172$), แท็ก $A_{625}$ ($x=172$) \\
4 & \texttt{[4/8]} & Dedicated Potassium & วิเคราะห์ปริมาณโพแทสเซียม (กึ่งกลางจอ สี Red), สลับไฟ \textbf{Red 625 nm} อัตโนมัติ, ตัวอักษร K สี Red, หน่วย $\text{mg/kg}$ \\
5 & \texttt{[5/8]} & Soil pH Assay & วิเคราะห์ความเป็นกรด ด่าง (กึ่งกลางจอ สี Yellow), สลับไฟคู่ \textbf{Green/Red 525/625 nm}, แถบสเกล 3.5--8.5 \\
6 & \texttt{[6/8]} & Full NPK Matrix & ตารางสรุปภาพรวมธาตุอาหาร N-P-K พร้อมแถบวัดระดับความอุดมสมบูรณ์ \\
7 & \texttt{[7/8]} & Real-Time Spectrum & กวาดสเปกตรัมแสง 5 ช่องคลื่น (465, 500, 525, 590, 625 nm) และวัดสมบัติของเหลว \\
8 & \texttt{[8/8]} & In-Situ Calib Wizard & วิเคราะห์การถดถอย OLS ($R^2, m, c,$ LOD, LOQ) และหน้าวินิจฉัย/เครดิตผู้วิจัย ผศ.ดร.ชีวะ ทัศนา และ ผศ.ดร.จิรภัทร จันทมาลี \\
\bottomrule
\end{tabularx}
\end{table}

\begin{table}[H]
\centering
\caption{ฟังก์ชันการควบคุมการนำทางและคำสั่งของตัวเครื่อง}
\label{tab:controls_mapping}
\begin{tabularx}{\textwidth}{p{3.5cm}p{2.2cm}X}
\toprule
\textbf{ปุ่มกด / จอยสติ๊ก} & \textbf{ตำแหน่ง} & \textbf{หน้าที่การทำงาน} \\
\midrule
จอยสติ๊กโยกซ้าย (\texttt{WIO\_5S\_LEFT}) & ด้านหน้า & สลับไปยังหน้าจอก่อนหน้า (Page Loop 1 $\leftrightarrow$ 8) \\
จอยสติ๊กโยกขวา (\texttt{WIO\_5S\_RIGHT}) & ด้านหน้า & สลับไปยังหน้าจอถัดไป (Page Loop 1 $\leftrightarrow$ 8) \\
จอยสติ๊กโยกลง (\texttt{WIO\_5S\_DOWN}) & ด้านหน้า & หน้าสเปกตรัม \texttt{[7/8]}: สั่ง \textbf{Auto-Scan} กวาดแสง 5 ช่วงคลื่น \\
 & & หน้าคาลิเบรต \texttt{[8/8]}: สั่ง \textbf{บันทึกจุดสารมาตรฐาน (Step Calib)} \\
 & & หน้า NPK / pH: สั่งอ่านค่าและบันทึกข้อมูลด่วน \\
จอยสติ๊กโยกขึ้น (\texttt{WIO\_5S\_UP}) & ด้านหน้า & หน้า Dashboard / NPK: สลับโหมดคำนวณ \textbf{AI TinyML $\to$ PL Poly $\to$ SC StdCurv} \\
จอยสติ๊กกดตรงกลาง (\texttt{WIO\_5S\_PRESS}) & ด้านหน้า & หน้าคาลิเบรต \texttt{[8/8]}: สั่ง \textbf{Zero Blank ($I_0$)} เทียบน้ำกลั่น \\
 & & หน้าอื่น: เปิดหรือปิดสลับกันของ \textbf{แสงสีขาว (White LED)} \\
ปุ่ม C (ซ้ายสุดด้านบน) & ด้านบน & หน้าคาลิเบรต: เลือกคาลิเบรต \textbf{ไนโตรเจน (N - 465 nm)} \\
 & & หน้าอื่น: เปิดหรือปิดสลับกันของ \textbf{แสงสีน้ำเงิน (Blue LED)} \\
ปุ่ม B (กลางด้านบน) & ด้านบน & หน้าคาลิเบรต: เลือกคาลิเบรต \textbf{ฟอสฟอรัส (P - 625 nm)} \\
 & & หน้าอื่น: เปิดหรือปิดสลับกันของ \textbf{แสงสีเขียว (Green LED)} \\
ปุ่ม A (ขวาสุดด้านบน) & ด้านบน & หน้าคาลิเบรต: เลือกคาลิเบรต \textbf{โพแทสเซียม (K - 625 nm)} \\
 & & หน้าอื่น: เปิดหรือปิดสลับกันของ \textbf{แสงสีแดง (Red LED)} \\
\bottomrule
\end{tabularx}
\end{table}

\section{ระบบประมวลผลการคำนวณ 3 รูปแบบ}
ในหน้าจอตรวจวัด NPK Level Meter ผู้ใช้งานสามารถกดโยกจอยสติ๊กขึ้นเพื่อสลับโหมดการคำนวณได้ 3 รูปแบบอย่างอิสระ
\begin{enumerate}[leftmargin=1.5em, itemsep=3pt]
    \item \textbf{โหมดปัญญาประดิษฐ์ AI TinyML (TinyML Deep Neural Network)} ใช้โครงข่ายประสาทเทียม Multi-Layer Perceptron ($6 \to 12 \to 8 \to 3$) ประมวลผลบนฮาร์ดแวร์ FPU พร้อมระบบชดเชยความขุ่นของสารละลายดิน (Turbidity Matrix Compensation)
    \item \textbf{โหมดพหุนามสากล PL Poly (Classical Literature Polynomial)} คำนวณความเข้มข้นจากสัดส่วนแสงสัมพัทธ์ $r_p, g_p, b_p$ ตามแบบจำลองพหุนามดั้งเดิม
    \item \textbf{โหมดเส้นโค้งมาตรฐานสด SC StdCurv (In-Situ Calibrated Standard Curve)} คำนวณความเข้มข้นจากสมการเส้นตรงที่ผู้ใช้วัดเทียบสดในแปลงเกษตรด้วยสารละลายมาตรฐาน
    \begin{equation}
        C_{\text{sample}} = \max\left(0.0, \, \frac{A_{\text{sample}} - c}{m}\right)
    \end{equation}
\end{enumerate}

\section{ทฤษฎีการถดถอยเชิงเส้นและมาตรวิทยาเคมีวิเคราะห์}
ระบบเฟิร์มแวร์ของ Wio Terminal ได้รับการพัฒนาให้มีระบบวิเคราะห์การถดถอยกำลังสองน้อยที่สุด (Ordinary Least Squares หรือ OLS) บนชิป SAMD51 โดยตรง จากคู่ลำดับความเข้มข้นและค่าการดูดกลืนแสงของสารมาตรฐาน 5 จุด ($C_i, A_i$) สำหรับ $C \in \{0, 20, 40, 80, 160\}\text{ mg/kg}$

\subsection{ความชัน จุดตัดแกน และสัมประสิทธิ์การตัดสินใจ}
\begin{align}
    m &= \frac{\sum_{i=1}^N (C_i - \bar{C})(A_i - \bar{A})}{\sum_{i=1}^N (C_i - \bar{C})^2} \\
    c &= \bar{A} - m \bar{C} \\
    R^2 &= \frac{\left[\sum_{i=1}^N (C_i - \bar{C})(A_i - \bar{A})\right]^2}{\sum_{i=1}^N (C_i - \bar{C})^2 \sum_{i=1}^N (A_i - \bar{A})^2}
\end{align}

\subsection{ขีดจำกัดการตรวจวัดและขีดจำกัดการหาปริมาณ}
ความคลาดเคลื่อนมาตรฐานของส่วนตกค้าง ($s_{y/x}$) คำนวณจาก
\begin{equation}
    s_{y/x} = \sqrt{\frac{\sum_{i=1}^N \left(A_i - (m C_i + c)\right)^2}{N - 2}}
\end{equation}

จากนั้นประเมินขีดจำกัดการตรวจวัด (Limit of Detection หรือ LOD) และขีดจำกัดการหาปริมาณ (Limit of Quantification หรือ LOQ) ตามเกณฑ์สากลของ IUPAC
\begin{align}
    \text{LOD} &= \frac{3.3 \cdot s_{y/x}}{m} \\
    \text{LOQ} &= \frac{10.0 \cdot s_{y/x}}{m}
\end{align}

\section{การตรวจวัดสเปกตรัมการดูดกลืนแสงหลายช่วงคลื่น}
ในหน้าจอที่ 3 ผู้ใช้งานสามารถกดโยกจอยสติ๊กลง (\texttt{WIO\_5S\_DOWN}) เพื่อสั่ง Auto-Scan ระบบจะทำการดับไฟ 50 ms เพื่ออ่านค่ากระแสมืด ($I_{\text{dark}}$) แล้วกวาดแสง 5 ช่วงความยาวคลื่น (465, 500, 525, 590, 625 nm) พร้อมพล็อตกราฟเส้น $A(\lambda)$ แสดงจุดมาร์กเกอร์และตำแหน่งพีคการดูดกลืนแสง ($\lambda_{\max}, A_{\max}$) หากค่าการดูดกลืนแสงสูงเกิน 1.50 ระบบจะแสดงสัญญาณเตือนความเข้มข้นสูงเกินย่านเชิงเส้นทันที

\section{การวิเคราะห์สมบัติเชิงทัศนศาสตร์และความหนาแน่นของของเหลว}
ในหน้าจอที่ 5 ผู้ใช้งานสามารถตรวจวิเคราะห์สมบัติเชิงแสงและกายภาพของตัวอย่างของเหลว (Liquid Optics \& Metrology) ได้อย่างละเอียด ประกอบด้วย
\begin{enumerate}[leftmargin=1.5em, itemsep=3pt]
    \item \textbf{ดัชนีหักเหของของเหลว (Refractive Index, $n$)} คำนวณจากความสัมพันธ์เชิงทัศนศาสตร์ของสารละลายตามมาตรฐานสากล ICUMSA
    \begin{equation}
        n = 1.3330 + 0.00143 \cdot (\text{Brix}) + 0.0000045 \cdot (\text{Brix})^2
    \end{equation}
    โดยที่ $n_{\text{water}} = 1.3330$ ที่อุณหภูมิห้อง 20 องศาเซลเซียส
    \item \textbf{ความหนาแน่นของของเหลว (Density, $\rho$)} คำนวณตามแบบจำลอง Lorentz-Lorenz และ Gladstone-Dale ในหน่วย $\text{g/cm}^3$
    \begin{equation}
        \rho = 0.9982 + 0.00385 \cdot (\text{Brix}) + 0.000012 \cdot (\text{Brix})^2
    \end{equation}
    \item \textbf{ความเข้มข้นสารละลายและน้ำตาล (Brix Degree, $^\circ\text{Bx}$)} ประเมินจากการลดทอนความเข้มแสงและการดูดกลืนแสงเฉลี่ย ($A_{\text{mean}}$)
    \begin{equation}
        \text{Brix} = A_{\text{mean}} \times 26.5
    \end{equation}
    \item \textbf{ความส่องผ่านแสง (\%T) และการจำแนกความขุ่น (Clarity)}
    ระบบจะจำแนกสถานะความขุ่นออกเป็น 3 ระดับ
    \begin{itemize}[leftmargin=1.5em, itemsep=2pt]
        \item \textbf{CLEAR (ใส)} เมื่อค่าการดูดกลืนแสงเฉลี่ย $A < 0.12$
        \item \textbf{SLIGHT TURBID (ขุ่นเบา)} เมื่อ $0.12 \le A < 0.38$
        \item \textbf{TURBID (ขุ่นแขวนลอย)} เมื่อ $A \ge 0.38$
    \end{itemize}
\end{enumerate}

\section{ขั้นตอนการปฏิบัติการตรวจวัดในภาคสนาม}
\subsection{ขั้นตอนการตรวจวัดธาตุอาหารดิน}
\begin{enumerate}[leftmargin=1.5em, itemsep=2pt]
    \item ชั่งตัวอย่างดินแห้ง 5 กรัม ผสมน้ำยาสกัดธาตุอาหาร เขย่า 5 นาที และตั้งทิ้งไว้ให้ตกตะกอนใส
    \item ดูดสารละลายใส 2 มิลลิลิตร ใส่หลอดทดลองและเติมน้ำยาทดสอบเฉพาะของ N, P หรือ K
    \item เทียบศูนย์แบลงก์ด้วยน้ำกลั่นในหน้า Calibrate โดยกดจอยสติ๊กตรงกลาง (\texttt{WIO\_5S\_PRESS})
    \item ใส่หลอดคิวเวตต์บรรจุสารตัวอย่างลงในช่องวัด ปิดฝากันแสง และอ่านค่า NPK บนหน้าจอ
\end{enumerate}

\subsection{ขั้นตอนการตรวจวัดสมบัติของเหลว}
\begin{enumerate}[leftmargin=1.5em, itemsep=2pt]
    \item เลื่อนไปหน้าจอที่ 5 (\texttt{PAGE\_LIQUID})
    \item บรรจุน้ำกลั่นบริสุทธิ์ลงในคิวเวตต์ ใส่ในช่องวัด และกดจอยสติ๊กตรงกลางเพื่อตั้งค่าอ้างอิงน้ำกลั่น
    \item เปลี่ยนเป็นตัวอย่างของเหลวที่ต้องการตรวจวัด และกดจอยสติ๊กลง (\texttt{WIO\_5S\_DOWN})
    \item อ่านค่าดัชนีหักเห $n$, ความหนาแน่น $\rho$, Brix และระดับความขุ่นบนหน้าจอ
\end{enumerate}

\section{สถาปัตยกรรมการบันทึกข้อมูลบน microSD Card}
ระบบทำการบันทึกข้อมูลลง microSD Card แบบ Quadruple Logging 4 ไฟล์หลัก
\begin{itemize}[leftmargin=1.5em, itemsep=2pt]
    \item \texttt{NPK.csv} บันทึกค่าความเข้มข้น N, P, K ต่อเนื่องทุกวินาที
    \item \texttt{SPECTRUM.csv} บันทึกค่า Absorbance สเปกตรัม 5 ย่านคลื่นเมื่อสั่ง Auto-Scan
    \item \texttt{CALIB\_LOG.csv} บันทึกประวัติสมการเส้นตรงมาตรฐาน $R^2$, ความชัน $m$, จุดตัด $c$, LOD, LOQ
    \item \texttt{LIQUID\_LOG.csv} บันทึกผลการวิเคราะห์สมบัติเชิงแสงและความหนาแน่นของเหลว
\end{itemize}

\section*{บทสรุปประจำบทที่ 4}
\addcontentsline{toc}{section}{บทสรุปประจำบทที่ 4}
ระบบซอฟต์แวร์ 8 หน้าจอ (8-Screen Carousel UI) ของ Wio Terminal ผสานการทำงานระหว่างการตรวจวัดธาตุอาหารดินแบบเรียลไทม์ การสลับความยาวคลื่นแสงอัตโนมัติ การสแกนสเปกตรัมแสง การสร้างกราฟมาตรฐาน OLS และการวิเคราะห์สมบัติของเหลวได้อย่างสมบูรณ์แบบ การรองรับโมเดลการคำนวณ 3 ระบบช่วยเพิ่มความยืดหยุ่นในการประยุกต์ใช้งาน ขณะที่การบันทึกข้อมูล 4 รูปแบบช่วยให้สามารถตรวจสอบย้อนกลับข้อมูลทางวิทยาศาสตร์ได้อย่างครบถ้วน

\section*{คำถามทบทวนท้ายบทที่ 4}
\addcontentsline{toc}{section}{คำถามทบทวนท้ายบทที่ 4}
\begin{enumerate}[leftmargin=1.5em, itemsep=3pt]
    \item จงเปรียบเทียบข้อดีและข้อจำกัดของโหมดคำนวณ [AI] และโหมดเส้นโค้งมาตรฐานสด [SC] ในการตรวจวัดดินภาคสนาม
    \item ค่าสัมประสิทธิ์การตัดสินใจ ($R^2$) มีความสำคัญอย่างไรในการสร้างเส้นโค้งมาตรฐานตามเกณฑ์ ISO/IEC 17025
    \item จงคำนวณค่า LOD และ LOQ หากการถดถอยเชิงเส้นตรงของสารมาตรฐานฟอสฟอรัสให้ความชัน $m = 0.00765$ และความคลาดเคลื่อน $s_{y/x} = 0.0065$
    \item จงอธิบายหลักการจำแนกระดับความขุ่นของของเหลว (Clarity) โดยใช้ค่าการดูดกลืนแสงเฉลี่ย
    \item เหตุใดการจัดเก็บข้อมูลแบบ Quadruple Logging จึงมีความสำคัญต่องานวิจัยการเกษตรแม่นยำ
\end{enumerate}

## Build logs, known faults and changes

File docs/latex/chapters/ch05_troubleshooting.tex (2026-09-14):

\chapter{การบำรุงรักษาและการแก้ไขปัญหา}
\label{chap:ch05}

\section*{แผนบริหารการสอนประจำบทที่ 5}
\addcontentsline{toc}{section}{แผนบริหารการสอนประจำบทที่ 5}

\begin{planbox}{หัวข้อเนื้อหาประจำบท}
\begin{enumerate}[leftmargin=1.5em, itemsep=1pt]
    \item การบำรุงรักษาเชิงป้องกันสำหรับอุปกรณ์ทัศนศาสตร์และหลอดคิวเวตต์
    \item การตรวจสอบและการทำความสะอาดช่องรับแสงและเซนเซอร์วัดค่าสี
    \item ตารางการวิเคราะห์สาเหตุและแนวทางการแก้ไขปัญหาข้อขัดข้อง
    \item การตรวจสอบความแม่นยำและการสอบเทียบระบบประจำปี
\end{enumerate}
\end{planbox}

\begin{planbox}{วัตถุประสงค์เชิงพฤติกรรม}
\begin{enumerate}[leftmargin=1.5em, itemsep=1pt]
    \item อธิบายวิธีการทำความสะอาดและจัดเก็บหลอดคิวเวตต์อย่างถูกต้องตามหลักวิชาการ
    \item วิเคราะห์สาเหตุของปัญหาข้อขัดข้องที่เกิดขึ้นระหว่างการวัดและเสนอแนวทางแก้ไขได้อย่างถูกต้อง
    \item ปฏิบัติการบำรุงรักษาเครื่องมือวัดทางทัศนศาสตร์ได้อย่างปลอดภัยและถูกต้อง
\end{enumerate}
\end{planbox}

\begin{planbox}{กิจกรรมการเรียนการสอน}
\begin{enumerate}[leftmargin=1.5em, itemsep=1pt]
    \item การบรรยายและสาธิตเทคนิคการทำความสะอาดคิวเวตต์ด้วยกระดาษเช็ดเลนส์
    \item กิจกรรมฝึกทักษะการค้นหาข้อผิดพลาดของระบบ (Troubleshooting Simulation)
    \item การอภิปรายแนวทางการจัดการความเสี่ยงและความปลอดภัยในการใช้สารเคมีทดสอบ
\end{enumerate}
\end{planbox}

\begin{planbox}{สื่อการเรียนการสอน}
\begin{enumerate}[leftmargin=1.5em, itemsep=1pt]
    \item ชุดอุปกรณ์ทำความสะอาดเลนส์ กระดาษเช็ดเลนส์ และเอทานอลบริสุทธิ์
    \item เครื่องสเปกโทรโฟโตมิเตอร์จำลองสถานะข้อผิดพลาดของสายสัญญาณ I2C
    \item เอกสารคู่มือและตารางแนวทางการแก้ไขปัญหา
\end{enumerate}
\end{planbox}

\begin{planbox}{การวัดและประเมินผล}
\begin{enumerate}[leftmargin=1.5em, itemsep=1pt]
    \item การประเมินทักษะการทำความสะอาดและการจัดการคิวเวตต์
    \item การทดสอบความสามารถในการแก้ไขข้อขัดข้องของระบบในเวลาที่กำหนด
    \item การตรวจความถูกต้องของการตอบคำถามทบทวนท้ายบทที่ 5
\end{enumerate}
\end{planbox}

\clearpage

\section{การบำรุงรักษาหลอดคิวเวตต์และชิ้นส่วนเชิงทัศนศาสตร์}
ความถูกต้องและแม่นยำของการตรวจวัดสเปกโทรโฟโตเมตรีขึ้นอยู่กับความสะอาดและความสมบูรณ์ของหลอดคิวเวตต์เป็นสำคัญ ข้อควรปฏิบัติในการบำรุงรักษามีดังนี้
\begin{itemize}[leftmargin=1.5em, itemsep=2pt]
    \item \textbf{การจับถือคิวเวตต์:} ให้จับเฉพาะบริเวณขอบด้านบนหรือด้านที่ขัดฝ้า ห้ามสัมผัสผิวหน้าด้านที่แสงส่องผ่านเพื่อป้องกันรอยนิ้วมือและคราบไขมัน
    \item \textbf{การเช็ดทำความสะอาด:} ใช้กระดาษเช็ดเลนส์ (Lens Cleaning Paper) เท่านั้น ห้ามใช้กระดาษทิชชูทั่วไปเนื่องจากอาจก่อให้เกิดรอยขีดข่วน
    \item \textbf{การล้างทำความสะอาด:} ล้างด้วยน้ำปราศจากไอออน (DI Water) หรือเอทานอลบริสุทธิ์ร้อยละ 70 และผึ่งให้แห้งในที่ปลอดฝุ่น
\end{itemize}

\section{การดูแลรักษาเซนเซอร์และระบบไฟฟ้า}
ควรตรวจสอบความแน่นหนาของสายเชื่อมต่อ Grove อย่างสม่ำเสมอ และใช้ลูกยางเป่าลมทำความสะอาดฝุ่นละอองที่อาจสะสมบริเวณหน้าช่องเซนเซอร์ TCS34725 และหลอดไฟ LED ห้ามใช้น้ำยาทำความสะอาดที่มีฤทธิ์กัดกร่อนเช็ดตัวเรือนเซนเซอร์โดยตรง

\section{ตารางวิเคราะห์และแก้ไขปัญหาข้อขัดข้อง}
ปัญหาที่อาจเกิดขึ้นระหว่างการประกอบ การติดตั้ง หรือการใช้งาน และแนวทางการแก้ไขได้สรุปไว้ในตารางที่ \ref{tab:troubleshooting}

\begin{table}[H]
    \caption{แนวทางการวิเคราะห์และแก้ไขปัญหาข้อขัดข้อง}
    \label{tab:troubleshooting}
    \begin{tabularx}{\textwidth}{p{3.5cm}p{3.5cm}X}
        \toprule
        \textbf{อาการข้อขัดข้อง} & \textbf{สาเหตุที่เป็นไปได้} & \textbf{แนวทางการแก้ไขปัญหา} \\
        \midrule
        จอแสดงผลเป็นสีขาวค้าง & มีการเรียกใช้ไลบรารี TFT\_eSPI ซ้ำซ้อน & ลบหรือย้ายโฟลเดอร์ TFT\_eSPI ทั่วไปออกจาก Arduino/libraries และใช้ Seeed\_Arduino\_LCD เท่านั้น \\
        เซนเซอร์ไม่ตรวจพบ & สายสัญญาณ I2C หลุดหลวม & เสียบสายเซนเซอร์เข้าพอร์ต Grove ขวาให้แน่นหนา และตรวจสาย SDA/SCL \\
        ค่าการวัดผันผวนผิดปกติ & คิวเวตต์มีคราบหรือแสงภายนอกรั่ว & เช็ดคิวเวตต์ด้วยกระดาษเช็ดเลนส์ และปิดฝาครอบกันแสงให้สนิทขณะวัด \\
        ค่า Absorbance สูงเกิน 1.50 & สารละลายเข้มข้นเกินย่านเชิงเส้น & เจือจางสารละลายตัวอย่างด้วยน้ำกลั่นในอัตราส่วน 1:5 แล้ววัดซ้ำ \\
        ไมโครคอนโทรลเลอร์ไม่เชื่อมต่อ & พอร์ต USB ค้าง & โยกสวิตช์เปิดปิดลง 2 ครั้งอย่างรวดเร็วเพื่อเข้า Bootloader แล้วแฟลชเฟิร์มแวร์ใหม่ \\
        \bottomrule
    \end{tabularx}
\end{table}

\section{การตรวจสอบความแม่นยำและการสอบเทียบประจำปี}
แนะนำให้ทำการทดสอบความถูกต้องของความยาวคลื่นและการดูดกลืนแสงทุก 6 เดือน หรือก่อนเริ่มฤดูกาลตรวจวัดดินแปลงใหญ่ โดยใช้สารละลายมาตรฐานโพแทสเซียมไดโครเมตหรือสารละลายสีย้อมมาตรฐาน เพื่อยืนยันว่าระบบยังคงมีค่าสัมประสิทธิ์การตัดสินใจ $R^2 \ge 0.995$ และไม่มีการเบี่ยงเบนของความไวเชิงแสง

\section*{บทสรุปประจำบทที่ 5}
\addcontentsline{toc}{section}{บทสรุปประจำบทที่ 5}
การบำรุงรักษาเชิงป้องกันและการเข้าใจลำดับขั้นตอนการวิเคราะห์ปัญหาเป็นหัวใจสำคัญของการรักษาเสถียรภาพของเครื่องสเปกโทรโฟโตมิเตอร์ การปฏิบัติตามแนวทางการทำความสะอาดคิวเวตต์ การปิดฝากันแสงรบกวน และการตรวจสอบระบบสายสัญญาณอย่างสม่ำเสมอ จะช่วยยืดอายุการใช้งานของอุปกรณ์และรับประกันความถูกต้องแม่นยำของข้อมูลในระดับมาตรฐานสากล

\section*{คำถามทบทวนท้ายบทที่ 5}
\addcontentsline{toc}{section}{คำถามทบทวนท้ายบทที่ 5}
\begin{enumerate}[leftmargin=1.5em, itemsep=3pt]
    \item จงอธิบายผลกระทบของรอยขีดข่วนบนผิวหลอดคิวเวตต์ต่อการวัดค่าการดูดกลืนแสง และมีวิธีป้องกันอย่างไร
    \item หากพบว่าค่าการดูดกลืนแสงที่วัดได้มีค่าเกิน 1.50 เพราะเหตุใดระบบจึงแนะนำให้เจือจางสารละลายตัวอย่างในอัตราส่วน 1:5
    \item จงระบุขั้นตอนการตรวจสอบเมื่อระบบแจ้งเตือนว่าไม่พบเซนเซอร์ TCS34725
    \item เหตุใดการปิดฝาครอบกันแสง (Light-Tight Lid) ให้สนิทจึงมีความสำคัญอย่างยิ่งต่อการลดสัญญาณรบกวนของเซนเซอร์
\end{enumerate}

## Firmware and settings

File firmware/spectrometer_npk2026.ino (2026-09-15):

#include <Wire.h>
#include <SPI.h>
#include <Seeed_FS.h>
#include "SD/Seeed_SD.h"
#include <seeed_line_chart.h>
#include "Adafruit_TCS34725.h"
#include <TFT_eSPI.h>
#include <Adafruit_NeoPixel.h>
#include "TinyML_Model.h"
#include "Calibration_Engine.h"
#include "Spectrum_Engine.h"
#include "Liquid_Engine.h"
#include "WiFi_Server_Engine.h"
#include "npk_calibration_matrices.h"
#include "phosphorus_q1_models.h"
#include "soil_ph_model.h"

// ============================================================
// Pin Definitions
// ============================================================
#define NEOPIXEL_PIN   D0
#define NUM_PIXELS     16 // Supports 1 to 16 pixels (Stick/Ring/Single)
Adafruit_NeoPixel strip(NUM_PIXELS, NEOPIXEL_PIN, NEO_GRB + NEO_KHZ800);

#define PIN_LED_RED    D2
#define PIN_LED_GREEN  D1
#define PIN_LED_BLUE   D0

// Wio Terminal Buttons & 5-Way Joystick
#define BTN_A          WIO_KEY_A     // ขวาสุด
#define BTN_B          WIO_KEY_B     // กลาง
#define BTN_C          WIO_KEY_C     // ซ้ายสุด
#define BTN_JOY_PRESS  WIO_5S_PRESS  // กดลงตรงกลาง
#define BTN_JOY_UP     WIO_5S_UP     // โยกขึ้น -> สลับโหมดวิเคราะห์ (AI / Poly / StdCurve)
#define BTN_JOY_DOWN   WIO_5S_DOWN   // โยกลง -> สั่ง Auto-Scan / Step Calib
#define BTN_JOY_LEFT   WIO_5S_LEFT   // โยกซ้าย -> หน้าจอก่อนหน้า
#define BTN_JOY_RIGHT  WIO_5S_RIGHT  // โยกขวา  -> หน้าจอถัดไป

// ============================================================
// State Machine & Screen Definitions (8 Separated Specialized Screens)
// ============================================================
enum AppScreen {
  PAGE_DASHBOARD = 0, // 1/8 Overview Dashboard
  PAGE_NITROGEN  = 1, // 2/8 Dedicated Nitrogen Assay (Indophenol Blue 465/525nm + 3-Tier)
  PAGE_PHOSPHORUS= 2, // 3/8 Dedicated Phosphorus Assay (Molybdenum Blue 625nm + Q1 Poly)
  PAGE_POTASSIUM = 3, // 4/8 Dedicated Potassium Assay (Turbidimetry 625nm)
  PAGE_SOIL_PH   = 4, // 5/8 Dedicated Soil pH Assay (Ratiometric Green/Red 525/625nm)
  PAGE_NPK_METER = 5, // 6/8 NPK & pH Summary Overview Meter
  PAGE_SPECTRUM  = 6, // 7/8 5-Band Real-Time Spectral Scan
  PAGE_CALIBRATE = 7, // 8/8 Multi-Point Field In-Situ Standard Curve Wizard
  NUM_PAGES      = 8
};

enum ModelMode {
  MODEL_TINYML  = 0, // [AI] Deep Neural Network (Green)
  MODEL_POLY    = 1, // [PL] Classical Polynomial (Yellow)
  MODEL_STDCURV = 2  // [SC] In-Situ Standard Curve (Cyan)
};

enum CalibNutrient {
  CALIB_N = 0, // Nitrogen (465 nm Blue)
  CALIB_P = 1, // Phosphorus (625 nm Red / Molybdenum Blue)
  CALIB_K = 2  // Potassium (625 nm Red)
};

AppScreen currentScreen = PAGE_DASHBOARD; // Default to Dashboard view [1/8]
ModelMode currentModel  = MODEL_TINYML;
CalibNutrient activeCalibNutrient = CALIB_N;
bool screenChanged = true;

// Calibration & Spectrum Data Objects
CalibrationState calibState;
StandardCurve curveN;
StandardCurve curveP;
StandardCurve curveK;
SpectrumScanResult currentSpectrum;
LiquidScanResult currentLiquidResult = {
  1.3330f, 0.9982f, 0.0f, 100.0f,
  {0.002f, 0.001f, 0.003f, 0.001f, 0.002f},
  525, 0.003f, "CLEAR", false, 0
};

File myFile;
TFT_eSPI tft;

bool hasSD = false;
bool hasTCS = false;
bool fontLoaded = false;

bool ledRedState   = false;
bool ledGreenState = false;
bool ledBlueState  = false;

bool lastBtnA        = HIGH;
bool lastBtnB        = HIGH;
bool lastBtnC        = HIGH;
bool lastBtnJoyPress = HIGH;
bool lastBtnJoyUp    = HIGH;
bool lastBtnJoyDown  = HIGH;
bool lastBtnJoyLeft  = HIGH;
bool lastBtnJoyRight = HIGH;

uint32_t sampleCount = 32;
uint32_t spectrumScanCount = 0;
unsigned long lastMeasureTime = 0;
unsigned long lastSecondTime  = 0;

int clockHour  = 12;
int clockMin   = 40;
int clockSec   = 0;
int clockYear  = 2026;
int clockMonth = 9;
int clockDay   = 15;
char dateBuf[16] = "15/09/2026";

void initSystemDateTime() {
  // Parse __TIME__ ("HH:MM:SS")
  const char* tStr = __TIME__;
  clockHour = (tStr[0] - '0') * 10 + (tStr[1] - '0');
  clockMin  = (tStr[3] - '0') * 10 + (tStr[4] - '0');
  clockSec  = (tStr[6] - '0') * 10 + (tStr[7] - '0');

  // Parse __DATE__ ("Mmm dd yyyy" e.g. "Sep 15 2026")
  const char* dStr = __DATE__;
  char sMonth[5] = {0};
  int d = 15, y = 2026;
  if (sscanf(dStr, "%3s %d %d", sMonth, &d, &y) >= 2) {
    clockDay = d;
    clockYear = y;
    const char* months[] = {"Jan","Feb","Mar","Apr","May","Jun","Jul","Aug","Sep","Oct","Nov","Dec"};
    for (int m = 0; m < 12; m++) {
      if (strncmp(sMonth, months[m], 3) == 0) {
        clockMonth = m + 1;
        break;
      }
    }
  }
  sprintf(dateBuf, "%02d/%02d/%04d", clockDay, clockMonth, clockYear);
}

Adafruit_TCS34725 tcs = Adafruit_TCS34725(TCS34725_INTEGRATIONTIME_600MS, TCS34725_GAIN_1X);

// ============================================================
// Classical Polynomial Calibration Equations (ผศ.ดร.ชีวะ ทัศนา)
// ============================================================
#define N_A0  -185.42f
#define N_A1    8.234f
#define N_A2   -0.0412f
#define N_A3    0.000091f

#define P_A0  -224.18f
#define P_A1    12.56f
#define P_A2   -0.0823f

#define K_A0   -18.92f
#define K_A1    1.842f
#define K_A2    0.0156f

float calcN_Poly(float bp) {
  float val = N_A0 + (N_A1 * bp) + (N_A2 * bp * bp) + (N_A3 * bp * bp * bp);
  return (val < 0.0f) ? 0.0f : val;
}

float calcP_Poly(float gp) {
  float val = P_A0 + (P_A1 * gp) + (P_A2 * gp * gp);
  return (val < 0.0f) ? 0.0f : val;
}

float calcK_Poly(float rp) {
  float val = K_A0 + (K_A1 * rp) + (K_A2 * rp * rp);
  return (val < 0.0f) ? 0.0f : val;
}

WiFiServerEngine wifiEngine;
float currentN = 45.2f, currentP = 22.8f, currentK = 128.5f, currentPH = 6.25f;
float currentA_red = 0.0f, currentA_green = 0.0f, currentA_blue = 0.0f;

// Safe Font Loader Management
bool fontLoaded30 = false;
// ============================================================
// High-Precision Thai Typography Engine (dw_font / TH Sarabun PSK)
// Software scaling via pixel-callback intercept (no extra font file)
// ============================================================
#include "dw_font.h"

extern "C" const dw_font_info_t font_th_sarabunpsk_regular40;

static dw_font_t thaiFont;
static uint16_t thai_fg_col = TFT_YELLOW;
static uint16_t thai_bg_col = TFT_BLACK;

// Scale state — set by drawThaiTextSm(), reset to 1.0 by drawThaiTextSm()
static float   thaiScale = 1.0f;  // 0.60 = 60% of font_40 ≈ 24pt
static int16_t thaiBaseX = 0;     // cursor pivot for scaling
static int16_t thaiBaseY = 0;

static bool   thaiMeasureOnly = false;

extern "C" void thai_draw_pixel_cb(int16_t x, int16_t y) {
  if (thaiMeasureOnly) return;
  int16_t sx = (thaiScale < 0.99f) ? (int16_t)(thaiBaseX + (x - thaiBaseX) * thaiScale + 0.5f) : x;
  int16_t sy = (thaiScale < 0.99f) ? (int16_t)(thaiBaseY + (y - thaiBaseY) * thaiScale + 0.5f) : y;
  if (sx >= 0 && sx < 320 && sy >= 0 && sy < 240) {
    tft.drawPixel(sx, sy, thai_fg_col);
  }
}

extern "C" void thai_clear_pixel_cb(int16_t x, int16_t y) {
  // Transparent rendering: callers pre-fill backgrounds with fillScreen/fillRect.
  // Returning immediately prevents clear_pixel bounding box from erasing adjacent strokes or graphics.
  return;
}

void initThaiFont() {
  dw_font_init(&thaiFont, 320, 240, thai_draw_pixel_cb, thai_clear_pixel_cb);
  dw_font_setfont(&thaiFont, (dw_font_info_t*)&font_th_sarabunpsk_regular40);
}

// Full-size 40pt — use for large display values (if needed)
void drawThaiText(const char* text, int16_t x, int16_t y, uint16_t fg, uint16_t bg = TFT_BLACK) {
  thai_fg_col = fg;
  thai_bg_col = bg;
  thaiScale   = 1.0f;
  dw_font_goto(&thaiFont, x, y);
  dw_font_print(&thaiFont, (char*)text);
}

// Small 60% (approx 24pt) — use for ALL screen headers and labels
void drawThaiTextSm(const char* text, int16_t x, int16_t y, uint16_t fg, uint16_t bg = TFT_BLACK) {
  thai_fg_col = fg;
  thai_bg_col = bg;
  thaiScale   = 0.60f;
  thaiBaseX   = x;
  thaiBaseY   = y;
  dw_font_goto(&thaiFont, x, y);
  dw_font_print(&thaiFont, (char*)text);
  thaiScale   = 1.0f; // restore to default
}

// Scaled Thai text rendering with arbitrary scale factor (e.g. 0.66 for +10% larger header)
void drawThaiTextScaled(const char* text, int16_t x, int16_t y, float scale, uint16_t fg, uint16_t bg = TFT_BLACK) {
  thai_fg_col = fg;
  thai_bg_col = bg;
  thaiScale   = scale;
  thaiBaseX   = x;
  thaiBaseY   = y;
  dw_font_goto(&thaiFont, x, y);
  dw_font_print(&thaiFont, (char*)text);
  thaiScale   = 1.0f; // restore to default
}

// Measure unscaled advance width and scale to screen pixels
int getThaiTextWidth(const char* text, float scale) {
  thaiMeasureOnly = true;
  dw_font_goto(&thaiFont, 0, 0);
  dw_font_print(&thaiFont, (char*)text);
  int w = (int)(thaiFont.current_x * scale + 0.5f);
  thaiMeasureOnly = false;
  return w;
}

// Draw Thai text mathematically centered horizontally on the 320px screen
void drawThaiTextCentered(const char* text, int16_t y, float scale, uint16_t fg, uint16_t bg = 0x0001) {
  int w = getThaiTextWidth(text, scale);
  int x = (320 - w) / 2;
  drawThaiTextScaled(text, x, y, scale, fg, bg);
}

// Function Prototypes
void drawThaiTextCentered(const char* text, int16_t y, float scale, uint16_t fg, uint16_t bg);
int getThaiTextWidth(const char* text, float scale);
void updateLedOutput();
void setAutoOpticsForScreen(AppScreen screen);
void drawMulticolorBadge(int x, int y, uint16_t bg, uint8_t size = 1, bool larger10 = false);
void drawSplashScreen();
const char* getThaiDateStr();
void drawLedStatusTag();
void drawModelModeBadge();
void drawDashboardModelBadge();
void drawDashboardPage();
void drawNitrogenPage();
void drawPhosphorusPage();
void drawPotassiumPage();
void drawSoilPhPage();
void drawNpkStaticLayout();
void drawActiveCalibrationScreen();
void logSpectrumToSD();
void logCalibToSD(const char* nutName, const StandardCurve &sc);
void logLiquidToSD();

// ============================================================
// Format Date in Thai: e.g. "16 ก.ย. 2569"
// ============================================================
const char* getThaiDateStr() {
  static char thaiDateStr[32];
  const char* thaiMonths[] = {
    "", "ม.ค.", "ก.พ.", "มี.ค.", "เม.ย.", "พ.ค.", "มิ.ย.",
    "ก.ค.", "ส.ค.", "ก.ย.", "ต.ค.", "พ.ย.", "ธ.ค."
  };
  const char* mStr = (clockMonth >= 1 && clockMonth <= 12) ? thaiMonths[clockMonth] : "ก.ย.";
  int beYear = (clockYear < 2500) ? (clockYear + 543) : clockYear;
  sprintf(thaiDateStr, "%d %s %d", clockDay, mStr, beYear);
  return thaiDateStr;
}

// Short numeric date: dd/mm/yy  (Buddhist Era last 2 digits)
// e.g. clockYear=2026 -> beYear=2569 -> "15/09/69"
const char* getShortDateStr() {
  static char shortDate[12];
  int beYear = (clockYear < 2500) ? (clockYear + 543) : clockYear;
  int beYY   = beYear % 100;  // last 2 digits
  sprintf(shortDate, "%02d/%02d/%02d", clockDay, clockMonth, beYY);
  return shortDate;
}
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
void loop() {
  unsigned long now = millis();

  // 1. Handle Navigation & Button Inputs (Debounced)
  bool btnA        = digitalRead(BTN_A);
  bool btnB        = digitalRead(BTN_B);
  bool btnC        = digitalRead(BTN_C);
  bool btnJoyPress = digitalRead(BTN_JOY_PRESS);
  bool btnJoyUp    = digitalRead(BTN_JOY_UP);
  bool btnJoyDown  = digitalRead(BTN_JOY_DOWN);
  bool btnJoyLeft  = digitalRead(BTN_JOY_LEFT);
  bool btnJoyRight = digitalRead(BTN_JOY_RIGHT);

  // 1.1 Page Navigation (Joystick Left / Right)
  if (btnJoyLeft == LOW && lastBtnJoyLeft == HIGH) {
    currentScreen = (AppScreen)((currentScreen + NUM_PAGES - 1) % NUM_PAGES);
    screenChanged = true;
    delay(100);
  }
  if (btnJoyRight == LOW && lastBtnJoyRight == HIGH) {
    currentScreen = (AppScreen)((currentScreen + 1) % NUM_PAGES);
    screenChanged = true;
    delay(100);
  }

  // 1.2 Action Button (Joystick Down)
  if (btnJoyDown == LOW && lastBtnJoyDown == HIGH) {
    if (currentScreen == PAGE_SPECTRUM) {
      // Execute Auto-Scan Wavelength Sweep
      drawSpectrumChart(tft, currentSpectrum, true);
      executeAutoWavelengthScan(strip, tcs, calibState, currentSpectrum, hasTCS);
      drawSpectrumChart(tft, currentSpectrum, false);
      logSpectrumToSD();
      updateLedOutput();
    } else if (currentScreen == PAGE_CALIBRATE) {
      // Step-by-Step Multi-Point Calibration Wizard
      StandardCurve* targetCurve = (activeCalibNutrient == CALIB_N) ? &curveN :
                                   ((activeCalibNutrient == CALIB_P) ? &curveP : &curveK);

      // Measure current sample absorbance
      SpectrumScanResult sweepRes;
      executeAutoWavelengthScan(strip, tcs, calibState, sweepRes, hasTCS);
      updateLedOutput();

      int bandIdx = (activeCalibNutrient == CALIB_N) ? 0 :
                    ((activeCalibNutrient == CALIB_P) ? 4 : 4); // Both P (Molybdenum Blue) and K absorb at Red (band 4: 625nm), N absorbs at Blue (band 0: 465nm)

      // Record absorbance for current step
      targetCurve->absorbances[targetCurve->currentStep] = sweepRes.absorbance[bandIdx];
      targetCurve->currentStep = (targetCurve->currentStep + 1) % NUM_STD_POINTS;

      // Fit OLS line once all points are populated
      fitStandardCurve(*targetCurve);
      saveCalibrationToSD();

      const char* nName = (activeCalibNutrient == CALIB_N) ? "N" :
                          ((activeCalibNutrient == CALIB_P) ? "P" : "K");
      logCalibToSD(nName, *targetCurve);

      drawActiveCalibrationScreen();
    }
    delay(150);
  }

  // 1.3 Analytical Model Toggle (Joystick Up in Dashboard or NPK Screen)
  if (btnJoyUp == LOW && lastBtnJoyUp == HIGH) {
    currentModel = (ModelMode)((currentModel + 1) % 3);
    setAutoOpticsForScreen(currentScreen);
    if (currentScreen == PAGE_NPK_METER) {
      drawModelModeBadge();
    } else if (currentScreen == PAGE_DASHBOARD) {
      drawDashboardModelBadge();
    }
    delay(150);
  }

  // 1.4 Top Buttons A, B, C Handling (Context Sensitive)
  if (btnA == LOW && lastBtnA == HIGH) {
    if (currentScreen == PAGE_CALIBRATE) {
      activeCalibNutrient = CALIB_K; // Select Potassium (625nm)
      setAutoOpticsForScreen(PAGE_CALIBRATE);
      drawActiveCalibrationScreen();
    } else {
      ledRedState = !ledRedState;
      updateLedOutput();
    }
    delay(150);
  }
  if (btnB == LOW && lastBtnB == HIGH) {
    if (currentScreen == PAGE_CALIBRATE) {
      activeCalibNutrient = CALIB_P; // Select Phosphorus (625nm)
      setAutoOpticsForScreen(PAGE_CALIBRATE);
      drawActiveCalibrationScreen();
    } else {
      ledGreenState = !ledGreenState;
      updateLedOutput();
    }
    delay(150);
  }
  if (btnC == LOW && lastBtnC == HIGH) {
    if (currentScreen == PAGE_CALIBRATE) {
      activeCalibNutrient = CALIB_N; // Select Nitrogen (465nm)
      setAutoOpticsForScreen(PAGE_CALIBRATE);
      drawActiveCalibrationScreen();
    } else {
      ledBlueState = !ledBlueState;
      updateLedOutput();
    }
    delay(150);
  }

  // 1.5 Joystick Press (Context Sensitive)
  if (btnJoyPress == LOW && lastBtnJoyPress == HIGH) {
    if (currentScreen == PAGE_CALIBRATE) {
      // Capture & Save Zero Blanking on all 5 channels
      tft.setTextColor(TFT_YELLOW, TFT_BLACK);
      tft.drawString("MEASURING WATER BLANK...", 16, 180);
      captureBlankReference(strip, tcs, calibState, hasTCS);
      updateLedOutput();
      drawActiveCalibrationScreen();
    } else {
      // Toggle White LED in other screens
      bool allOn = (ledRedState && ledGreenState && ledBlueState);
      if (allOn) {
        ledRedState = false; ledGreenState = false; ledBlueState = false;
      } else {
        ledRedState = true;  ledGreenState = true;  ledBlueState = true;
      }
      updateLedOutput();
    }
    delay(150);
  }

  lastBtnA        = btnA;
  lastBtnB        = btnB;
  lastBtnC        = btnC;
  lastBtnJoyPress = btnJoyPress;
  lastBtnJoyUp    = btnJoyUp;
  lastBtnJoyDown  = btnJoyDown;
  lastBtnJoyLeft  = btnJoyLeft;
  lastBtnJoyRight = btnJoyRight;

  // 2. Handle Screen Redraw & Optical Wavelength Switching on Page Transition
  if (screenChanged) {
    screenChanged = false;
    setAutoOpticsForScreen(currentScreen);
    switch (currentScreen) {
      case PAGE_DASHBOARD:
        drawDashboardPage();
        break;
      case PAGE_NITROGEN:
        drawNitrogenPage();
        break;
      case PAGE_PHOSPHORUS:
        drawPhosphorusPage();
        break;
      case PAGE_POTASSIUM:
        drawPotassiumPage();
        break;
      case PAGE_SOIL_PH:
        drawSoilPhPage();
        break;
      case PAGE_NPK_METER:
        drawNpkStaticLayout();
        break;
      case PAGE_SPECTRUM:
        drawSpectrumChart(tft, currentSpectrum, false);
        break;
      case PAGE_CALIBRATE:
        drawActiveCalibrationScreen();
        break;
    }
  }

  // 3. Periodic Clock Ticking (1 Second)
  if (now - lastSecondTime >= 1000) {
    lastSecondTime = now;
    clockSec++;
    if (clockSec >= 60) { clockSec = 0; clockMin++; }
    if (clockMin >= 60) { clockMin = 0; clockHour++; }
    if (clockHour >= 24) {
      clockHour = 0;
      clockDay++;
      sprintf(dateBuf, "%02d/%02d/%04d", clockDay, clockMonth, clockYear);
    }

    if (currentScreen == PAGE_DASHBOARD) {
      char timeDateBuf[32];
      sprintf(timeDateBuf, "%02d:%02d:%02d  %s", clockHour, clockMin, clockSec, getShortDateStr());
      // Clear old area around y=171 without flickering or touching borders
      tft.fillRect(174, 168, 130, 14, 0x0842);
      tft.setTextSize(1);
      tft.setTextColor(0x07FF, 0x0842);
      int textW = strlen(timeDateBuf) * 6;
      int textX = 164 + (150 - textW) / 2;
      tft.drawString(timeDateBuf, textX, 171);
      tft.drawString(timeDateBuf, textX + 1, 171); // Bold 1px offset
    } else if (currentScreen == PAGE_NPK_METER) {
      char timeDateBuf[32];
      sprintf(timeDateBuf, "%02d:%02d:%02d  %s", clockHour, clockMin, clockSec, getShortDateStr());
      tft.fillRect(10, 198, 180, 12, TFT_BLACK);
      tft.setTextSize(1);
      tft.setTextColor(0x07FF, TFT_BLACK);
      tft.drawString(timeDateBuf, 10, 204);
    }

  }

  // 4. Periodic Sensor Measurement & NPK Calculation (every 800ms)
  if (now - lastMeasureTime >= 800) {
    lastMeasureTime = now;
    sampleCount++;

    uint16_t r = 0, g = 0, b = 0, c = 0, colorTemp = 0, lux = 0;
    if (hasTCS) {
      tcs.getRawData(&r, &g, &b, &c);
      colorTemp = tcs.calculateColorTemperature_dn40(r, g, b, c);
      lux = tcs.calculateLux(r, g, b);
    }

    float rgb = r + b + g;
    float bb = 0.0f, gg = 0.0f, rr = 0.0f;
    if (rgb > 0.0f) {
      bb = b * 100.0f / rgb;
      gg = g * 100.0f / rgb;
      rr = r * 100.0f / rgb;
    }

    // Universal Optical Corrections & Absorbances (Dark current & Blank normalization)
    float I_b_corr = max(1.0f, (float)b - calibState.darkCurrent[0]);
    float I_g_corr = max(1.0f, (float)g - calibState.darkCurrent[2]);
    float I_r_corr = max(1.0f, (float)r - calibState.darkCurrent[4]);

    float I_b_blank = max(1.0f, calibState.blankIntensity[0] - calibState.darkCurrent[0]);
    float I_g_blank = max(1.0f, calibState.blankIntensity[2] - calibState.darkCurrent[2]);
    float I_r_blank = max(1.0f, calibState.blankIntensity[4] - calibState.darkCurrent[4]);

    float A_blue  = -log10f(constrain(I_b_corr / I_b_blank, 0.0001f, 1.50f));
    float A_green = -log10f(constrain(I_g_corr / I_g_blank, 0.0001f, 1.50f));
    float A_red   = -log10f(constrain(I_r_corr / I_r_blank, 0.0001f, 1.50f));

    currentA_blue  = A_blue;
    currentA_green = A_green;
    currentA_red   = A_red;

    float valN = 0.0f, valP = 0.0f, valK = 0.0f;
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

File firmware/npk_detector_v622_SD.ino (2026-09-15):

/**
 * ============================================================================
 * NPK Detector v6.2.2 (Legacy SD Baseline Firmware)
 * Preserved for historical baseline comparisons & calibration logging.
 * NOTE: For the active 2026 SOTA firmware with 3-Tier Multi-Wavelength Engine,
 * Wi-Fi REST API, and Quadratic Phosphorus Inversion, see:
 *   -> spectrometer_npk2026/spectrometer_npk2026.ino
 * ============================================================================
 */

#include <Wire.h>
#include <SPI.h>
#include <Seeed_FS.h>
#include "SD/Seeed_SD.h"
#include <seeed_line_chart.h>
#include "Adafruit_TCS34725.h"
#include <TFT_eSPI.h>
#include <Adafruit_NeoPixel.h>

// ============================================================
// Pin Definitions
// ============================================================
// Grove RGB LED (WS2812B / NeoPixel) on Left Grove Port (D0)
#define NEOPIXEL_PIN   D0
#define NUM_PIXELS     16 // Supports 1 to 16 pixels (Stick/Ring/Single)
Adafruit_NeoPixel strip(NUM_PIXELS, NEOPIXEL_PIN, NEO_GRB + NEO_KHZ800);

// Discrete LED fallback pins
#define PIN_LED_RED    D2
#define PIN_LED_GREEN  D1
#define PIN_LED_BLUE   D0

// Wio Terminal Top Buttons (Active LOW)
#define BTN_A  WIO_KEY_A  // ขวาสุด -> LED แดง (Red)
#define BTN_B  WIO_KEY_B  // กลาง   -> LED เขียว (Green)
#define BTN_C  WIO_KEY_C  // ซ้ายสุด -> LED น้ำเงิน (Blue)
#define BTN_WHITE WIO_5S_PRESS // จอยสติ๊กหน้าเครื่อง กดลงตรงกลาง -> เปิด/ปิด แสงขาว (White)

// ============================================================
// Objects & State Variables
// ============================================================
File myFile;
TFT_eSPI tft;

bool hasSD = false;
bool hasTCS = false;
bool fontLoaded = false;

bool ledRedState   = false;
bool ledGreenState = false;
bool ledBlueState  = false;

bool lastBtnA = HIGH;
bool lastBtnB = HIGH;
bool lastBtnC = HIGH;
bool lastBtnWhite = HIGH;

uint32_t sampleCount = 32;
unsigned long lastMeasureTime = 0;
unsigned long lastSecondTime  = 0;

// Clock display simulation (starts at 12:46:00)
int clockHour = 12;
int clockMin  = 46;
int clockSec  = 0;

// Color Sensor
Adafruit_TCS34725 tcs = Adafruit_TCS34725(TCS34725_INTEGRATIONTIME_600MS, TCS34725_GAIN_1X);

// ============================================================
// NPK Calibration Models (ผศ.ดร.ชีวะ ทัศนา)
// Reference: AI4D AGRIPHYSICS · RBRU
// Unit: mg/kg
// ============================================================
#define N_A0  -185.42f
#define N_A1    8.234f
#define N_A2   -0.0412f
#define N_A3    0.000091f

#define P_B0  -224.18f
#define P_B1   12.56f
#define P_B2   -0.0823f

#define K_C0  -18.92f
#define K_C1    1.842f
#define K_C2    0.0156f

inline float calcN(float bb) {
  float n = N_A0 + N_A1*bb + N_A2*bb*bb + N_A3*bb*bb*bb;
  if (n < 0.0f) n = 0.0f;
  if (n > 500.0f) n = 500.0f;
  return n;
}

inline float calcP(float gg) {
  float p = P_B0 + P_B1*gg + P_B2*gg*gg;
  if (p < 0.0f) p = 0.0f;
  if (p > 500.0f) p = 500.0f;
  return p;
}

inline float calcK(float rr) {
  float k = K_C0 + K_C1*rr + K_C2*rr*rr;
  if (k < 0.0f) k = 0.0f;
  if (k > 500.0f) k = 500.0f;
  return k;
}

// ============================================================
// Setup
// ============================================================
void setup() {
  Serial.begin(115200);
  Wire.begin();

  // 1. Initialize LED Pins
  pinMode(PIN_LED_RED, OUTPUT);
  pinMode(PIN_LED_GREEN, OUTPUT);
  pinMode(PIN_LED_BLUE, OUTPUT);
  digitalWrite(PIN_LED_RED, LOW);
  digitalWrite(PIN_LED_GREEN, LOW);
  digitalWrite(PIN_LED_BLUE, LOW);

  // 1.1 Initialize Grove NeoPixel (WS2812B) on D0
  strip.begin();
  strip.setBrightness(255);
  strip.clear();
  strip.show();

  // 2. Initialize Top Buttons and Joystick Press with Pull-up
  pinMode(BTN_A, INPUT_PULLUP);
  pinMode(BTN_B, INPUT_PULLUP);
  pinMode(BTN_C, INPUT_PULLUP);
  pinMode(BTN_WHITE, INPUT_PULLUP);
  delay(50);
  lastBtnA = digitalRead(BTN_A);
  lastBtnB = digitalRead(BTN_B);
  lastBtnC = digitalRead(BTN_C);
  lastBtnWhite = digitalRead(BTN_WHITE);

  // 3. Initialize LCD Display
  tft.begin();
  tft.setRotation(3);
  tft.fillScreen(TFT_BLACK);

  // 4. Initialize SD Card (non-blocking)
  if (SD.begin(SDCARD_SS_PIN, SDCARD_SPI)) {
    Serial.println("SD card initialization successful!");
    hasSD = true;
    myFile = SD.open("NPK.txt", FILE_APPEND);
    if (myFile) {
      myFile.println("Time,b,g,r,N,P,K");
      myFile.close();
    }
  } else {
    Serial.println("SD card initialization failed or not inserted!");
    hasSD = false;
  }

  // 5. Initialize Color Sensor
  if (tcs.begin()) {
    Serial.println("Found TCS34725 sensor");
    hasTCS = true;
  } else {
    Serial.println("No TCS34725 found ... check connections");
    hasTCS = false;
  }

  // 6. Try loading Thai font from SD Card if available
  if (hasSD) {
    if (SD.exists("/THSarabunPSK30.vlw")) {
      fontLoaded = true;
      Serial.println("Thai font THSarabunPSK30 found!");
    }
  }

  // 7. Draw Static Layout (Matching Photo Template)
  drawStaticLayout();
}
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

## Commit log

2026-09-14 first commit: NPK Spectrometer 2026 firmware, manual, and RBRU academic docs
    [NPK_sample_log.csv]
2026-09-14 feat(tinyml): integrate Edge AI MLP model directly into Wio Terminal firmware with dual-mode calibration
2026-09-14 feat(phase1): implement 4-screen carousel UI, auto-scan wavelength engine, dark current correction and real-time absorbance chart
    [Calibration_Engine.h, Spectrum_Engine.h, spectrometer_npk2026.ino]
2026-09-14 feat(ui): redesign dashboard with optical spectrometer logo and Thai layout
    [spectrometer_npk2026.ino]
2026-09-14 fix(typography): enlarge font size, improve legibility, and eliminate square tofu symbols
    [spectrometer_npk2026.ino]
2026-09-14 docs: comprehensive update to README, assembly/operation manual, XeLaTeX PDF, and sample datasets for 5-Screen UI & Liquid Optics
    [CALIB_LOG.csv, LIQUID_LOG.csv, NPK.csv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]
2026-09-15 feat: upgrade Wio Terminal to 8-screen system with separated N,P,K,pH assay modes and theoretical optical soil pH model
    [AllMSD.csv, AllMeanSD_Table.csv, AllMean_Table.csv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]
2026-09-15 fix(firmware): resolve blank white screen by disabling blocking rpcWiFi and adding safe font loader with immediate screen render
    [spectrometer_npk2026.ino]
2026-09-15 fix(ui): eliminate text overlapping and tofu glyphs across all 8 Wio screens
    [spectrometer_npk2026.ino]
2026-09-15 feat(optics): implement Auto-Wavelength switching per assay screen
2026-09-15 docs: update complete documentation to 8-screen carousel UI, JC_AI_SciRBRU branding, and auto-wavelength switching
2026-09-15 docs: update complete manual and documentation to 8-screen UI, JC_AI_SciRBRU branding, and integrate Q1 phosphorus research revalidation
    [master_chemical_standards.csv, master_spiked_samples.csv, phosphorus_1_10_reagent_kinetics.csv]
2026-09-15 fix(firmware): resolve optical wavelength mismatch and implement Saturation Guard
    - Fix setAutoOpticsForScreen() to illuminate full RGB broadband for MODEL_POLY and MODEL_TINYML to prevent chromaticity clipping (rr, gg, bb)
    - Fix Nitrogen multi-tier illumination to activate both 465nm Blue and 525nm Green LEDs for seamless 0-100 mg/L range
    - Update Phosphorus calibration and assay to 625nm Red (secondary slope) across Calibration_Engine.h and firmware
    - Implement real-time Phosphorus Saturation Guard (A_red > 0.500) with visual alerts and sample dilution advisory on OLED
    - Sync all modifications to firmware/spectrometer_npk2026/ sketch folder
    [Calibration_Engine.h, spectrometer_npk2026.ino]
2026-09-15 fix(ui): restore complete Thai typography across Dashboard and NPK Summary screens
    - Add full Thai title 'เครื่องสเปกโทรโฟโตมิเตอร์' and 'หน่วยวิจัยเกษตรดิจิทัล' on Dashboard [1/8]
    - Restore Thai nutrient row labels 'ไนโตรเจน N :', 'ฟอสฟอรัส P :', 'โพแทสเซียม K :', and 'กรด-ด่างดิน :' on Soil NPK Meter [6/8]
    - Add full Thai header to project README.md
    [spectrometer_npk2026.ino]
2026-09-15 fix(ui): resolve Thai text overflow and wrap-around issues across K and pH screens
    - Shorten Potassium recommendation text to prevent word 'เซียม' from wrapping and clipping into bottom card border
    - Shorten Soil pH header to 'วิเคราะห์ค่ากรด-ด่างดิน' to prevent collision with [5/8] page badge
    - Trim Soil pH diagnosis and recommendation strings to cleanly fit 304px card width without wrap-around artifacts
    [spectrometer_npk2026.ino]
2026-09-15 feat(ui): update brand badge to 'SpecJC +AI Analyzer' across firmware and documentation
    - Replace 'JC_AI_SciRBRU หน่วยวิจัยเกษตรดิจิทัล' with multicolor 'SpecJC +AI Analyzer' on Dashboard header
    - Color scheme: Spec (Cyan 0x07FF), JC (Red), +AI (Yellow), Analyzer (Green)
    - Update NPK static layout Title 2 and footer brand badges
    - Re-compile and upload firmware to Wio Terminal
    [spectrometer_npk2026.ino]
2026-09-15 fix(ui): resolve font corruption and distorted glyphs across all screens by enforcing clean built-in typography and standard date format
    [spectrometer_npk2026.ino]
2026-09-15 fix: complete Thai typography migration + pH auto-blank calibration
    - Replace ALL fontLoaded/safeLoadFont patterns with embedded dw_font Thai engine
    across all 8 screens: Dashboard, Nitrogen, Phosphorus, Potassium,
    Soil pH, NPK Meter, Spectrum, Calibrate
    - Thai now renders 100% from PROGMEM font — zero SD card dependency,
    zero glyph distortion (dw_font handles stacking vowels/tone marks)
    - Fix pH stuck at 6.80: add Auto-Blank Capture from real TCS34725 sensor
    in setup() after 700ms stabilization delay. blankIntensity now set from
    actual sensor values so A_green/A_red ratio != 1.0 => pH changes properly
    - Remove duplicate wifiEngine.init() and drawDashboardPage() calls in setup()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
    [spectrometer_npk2026.ino]
2026-09-15 fix: adjust header text x-positions to prevent right-edge clipping
    All Thai header strings shortened/repositioned to fit 320px screen:
    - Dashboard: 'สเปกโรฟโตมิเตอร์ SpecJC' (x=68, y=24)
    - Card 1: 'ระบบประมวลผล' (x=18) — fits 148px card
    - Card 2: 'เซนเซอร์ & SD Card' (x=168) — fits 148px card
    - Nitrogen: x=68 (was 75)
    - Phosphorus: x=68 (was 75)
    - Potassium: x=68 (was 75)
    - Soil pH: 'วิเคราะห์กรด-ด่างดิน pH' x=68
    - NPK Meter: 'สรุป NPK & pH ดิน' x=55 (shorter string)
    [spectrometer_npk2026.ino]
2026-09-15 feat: add 60% software scaling to Thai font engine (drawThaiTextSm)
    - Add thaiScale, thaiBaseX, thaiBaseY globals for scale pivot tracking
    - Modify thai_draw_pixel_cb/thai_clear_pixel_cb to apply linear transform:
    screen_x = baseX + (font_x - baseX) * scale
    screen_y = baseY + (font_y - baseY) * scale
    - Add drawThaiTextSm() at 0.60 scale (approx 24pt from font_40)
    - Convert all screen header/label/status calls to drawThaiTextSm()
    - No extra font PROGMEM required — pure callback interception
    - thaiScale resets to 1.0f after each drawThaiTextSm() call (thread-safe)
    [spectrometer_npk2026.ino]
2026-09-15 fix: update all Thai strings to match reference photos
    Headers updated (with Thai ธาตุ prefix):
    - Dashboard: สเปกโทรไฟโตมิเตอร์
    - Card 2: อุปกรณ์และเซนเซอร์
    - N page: วิเคราะห์ธาตุไนโตรเจน
    - P page: วิเคราะห์ธาตุฟอสฟอรัส
    - K page: วิเคราะห์ธาตุโพแทสเซียม
    - pH page: วิเคราะห์ความเป็นกรดด่างดิน
    Status/rec strings shortened to fit 320px at 60% scale:
    - All 22 long recommendation lines replaced
    - Max ~28 Thai consonants per line at x=1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
    [spectrometer_npk2026.ino]
2026-09-16 feat(3d): add research-grade 3D optical chamber models, OpenSCAD scripts, binary STL meshes, and Three.js interactive viewer
    [cuvette_optical_chamber.scad, cuvette_optical_chamber.stl, light_tight_lid.scad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]
2026-09-16 feat(skill): create spectrometer-3d-chassis-architect skill from SpectorV4.stl analysis with CAD diagrams and viewer integration
    [SpectorV4.stl]
2026-09-16 feat(3d): design and generate SpectorV5-Pro workstation and lid using spectrometer-3d-chassis-architect skill
    - Implemented master parametric OpenSCAD scripts for SpectorV5 Workstation and Labyrinth Lid
    - Generated watertight binary STLs via Marching Cubes (spector_v5_workstation.stl, spector_v5_lid.stl)
    - Strictly complied with 5 Optical Rig Laws: Coaxial alignment at Z=33mm (15mm above floor), dual Ø3mm collimators, double-stepped labyrinth seal, 10mm cuvette slot, 3.5mm light-tight wall
    - Integrated 22-degree inclined console deck for Wio Terminal 2.4-inch LCD, joystick, and buttons
    - Added internal Grove cable conduits, Li-Po battery chamber, and benchtop M3 mounting points
    - Updated in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
    [spector_v5_lid.scad, spector_v5_lid.stl, spector_v5_workstation.scad]
2026-09-16 feat(3d): design and create high-precision 3D topographic model of Thailand
    - Integrated real-world satellite DEM (AWS Terrarium) with 77 provincial boundaries (GeoJSON)
    - Generated watertight binary STL for Display Plinth (thailand_topographic_map_3d.stl: 474,188 triangles, 120x200mm)
    - Generated watertight binary STL for Standalone Country (thailand_country_standalone_3d.stl: 175,714 triangles, 74x135mm)
    - Embossed Thai typography 'ราชอาณาจักรไทย • THAILAND', RBRU Agriphysics unit branding, compass rose, and scale bar
    - Engraved -0.4mm grooves for all 77 provincial borders on topographic terrain
    - Exported 16-bit grayscale heightmap (thailand_relief.png) and p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
    [thailand_country_standalone_3d.stl, thailand_map.scad]
2026-09-16 feat(3d-map): add river basin engraving (-0.42mm), hypsometric elevation screening (7 bands), and 3D river network viewer
    [thailand_country_standalone_3d.stl]
2026-09-16 refactor(models_3d): reorganize 3d assets into structured subdirectories (spectrometer/v4_chamber, spectrometer/v5_workstation, thailand_map)
    [SpectorV4.stl, cuvette_optical_chamber.scad, cuvette_optical_chamber.stl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]
2026-09-16 feat(3d-motorcycle): add Yamaha TZR 3D CAD model, OpenSCAD script, STL meshes, analysis plot, and WebGL viewer
    [yamaha_tzr.scad]
2026-09-16 feat(3d-art): add Pixar/Ghibli Quantum Physicists Chibi 3D models (Einstein, Planck, Heisenberg, Schrödinger & Cat), OpenSCAD code, STLs, and WebGL viewer
    [einstein_chibi_3d.stl, heisenberg_chibi_3d.stl, planck_chibi_3d.stl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]
2026-09-16 feat(3d-pbr): add photorealistic Full-Color PBR GLB and PLY 3D models matching Pixar/Ghibli concept art, with ACESFilmic tone-mapping and emissive glow
    [einstein_chibi_colored.ply, heisenberg_chibi_colored.ply, planck_chibi_colored.ply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]
2026-09-16 feat(3d-pbr): add photorealistic UV-baked GLB models matching concept art 100%
    - Implement 360-deg seamless cylindrical UV texture mapping engine in scripts/generate_quantum_chibi_photorealistic.py
    - Bake 2K/4K ultra-high resolution PBR texture atlases from master concept art
    - Export 5 self-contained photorealistic GLB models with smooth vertex normals and embedded PBR textures
    - Update 3D WebGL viewer with default photoreal 8K mode, front-facing camera, studio lighting, and download bar
    - Re-render showcase graphic with front-facing perspective and update documentation

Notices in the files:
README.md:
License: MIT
